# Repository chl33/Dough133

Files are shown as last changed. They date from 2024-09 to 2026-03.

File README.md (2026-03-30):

# Dough133 (v1.0.0)

Dough133 is a temperature-controlled container for proofing and fermenting sourdough.
It uses a small cooler and a PTC heater with a fan to heat the inside of the cooler.
A PCBA with an ESP32 controls the power supplied to the heater to regulate
 the temperature of the enclosure.

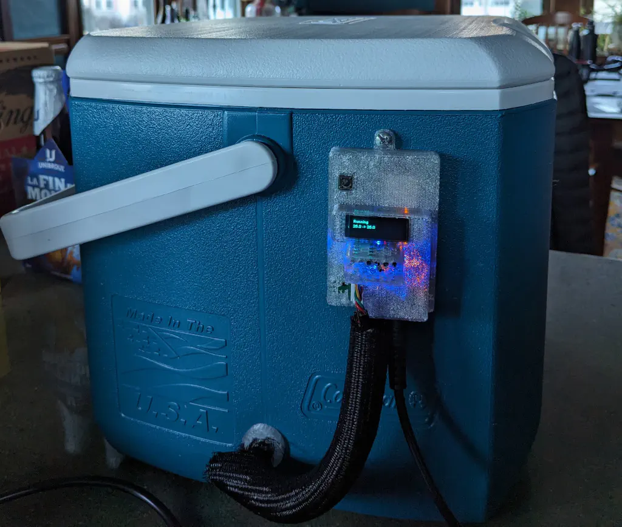
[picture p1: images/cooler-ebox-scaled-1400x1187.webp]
Doughh133


This repository contains:
- KiCAD design for the PCB.
- Source code for the device firmware.
- OpenSCAD design for 3D printed components.

[Instructions for the assembly](https://selectiveappeal.org/posts/dough133-assembly/)
 of the device are in this are at my blog.

Please also see the other entries describing this project:
- [Building a DIY Sourdough Proofer (Dough133)](https://selectiveappeal.org/posts/dough133/),
- [Dough133 Electronics: Designing a Custom ESP32 Controller for Proofing Sourdough](https://selectiveappeal.org/posts/dough133-electronics/), and
- [Dough133 Control: Yeast Welfare through Applied Mathematics](https://selectiveappeal.org/posts/dough133-control/).

Components needed for making this device, along with links and approximate price as of September
 2024:

| Item | Source  | Approximate cost  |
|---|---|---|
| Coleman 16 qt cooler | [Amazon](https://www.amazon.com/gp/product/B09HN13FN4) | $23 |
| PTC Air Heater 12V 100W | [AliExpress](https://www.aliexpress.us/item/3256803451720173.html) | $7 |
| DC 12V 5A Power Supply | [Amazon](https://www.amazon.com/gp/product/B01GEA8PQA)  | $12  |

## KiCAD

The circuit board design is in [KiCAD/](KiCAD/).

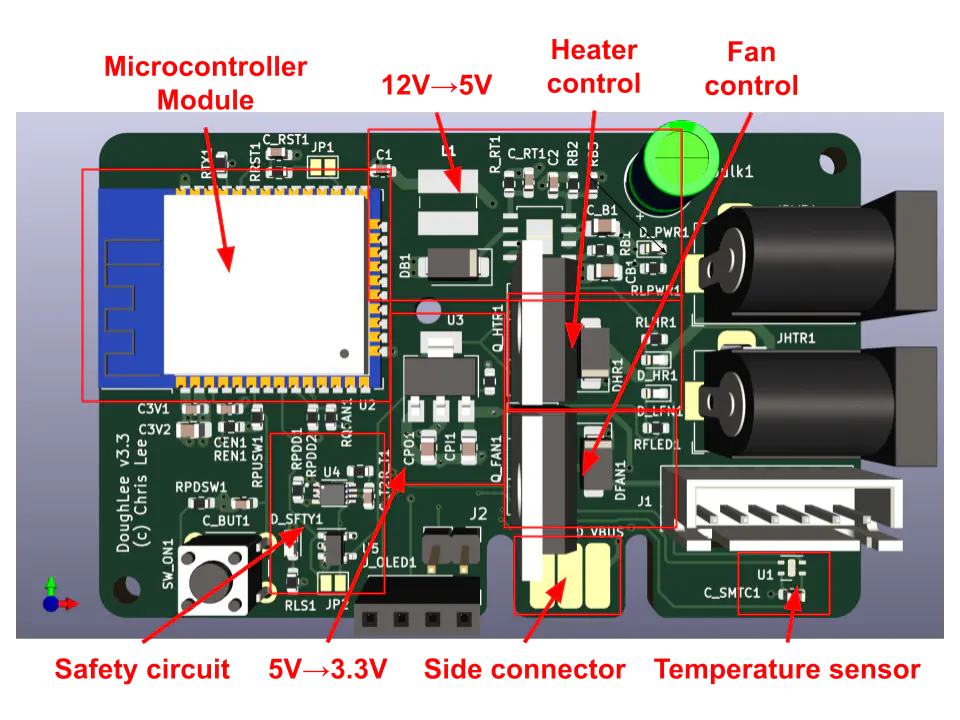
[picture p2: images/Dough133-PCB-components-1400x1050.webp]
Circuit board


These require footprints in [`chl33_library`](https://github.com/chl33/chl33_library.pretty) and symbols in [`chl33_kicad_sym`](https://github.com/chl33/chl33_kicad_sym).

## OpenSCAD

Designs for 3D-printable components are in [scad/](scad/).

The EBox is based on the [ProjectBox](https://github.com/chl33/ProjectBox) OpenSCAD system.

The heater mount secures the heater and temperature/humidity sensor inside the cooler.

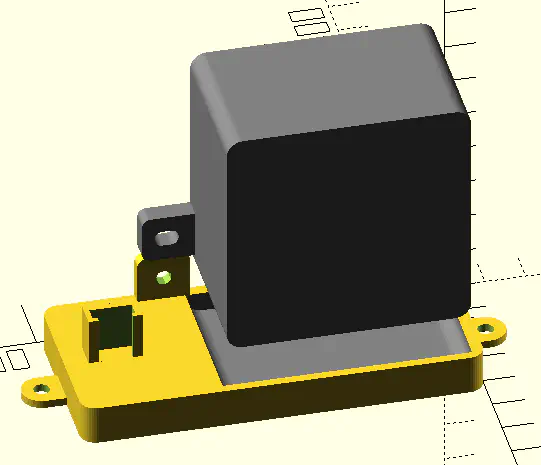
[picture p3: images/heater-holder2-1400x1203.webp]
Heater mount


The Cooler plug helps avoid heat leaking through the hole through which wires run from the
 heater mount through the wall of the cooler to the EBox.

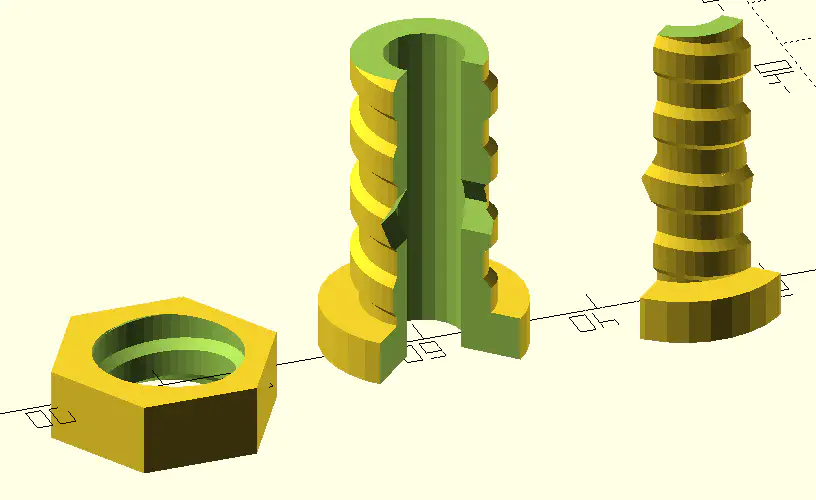
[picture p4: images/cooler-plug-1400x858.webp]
Cooler plug


## Software

The software is based on the [og3](https://github.com/chl33/og3) library and built
 using [PlatformIO](https://platformio.org/).

### Features

*   **Modern Web Interface:** A responsive Svelte-based UI for real-time status monitoring, PID tuning, and system configuration.
*   **PID Temperature Control:** Uses a Proportional-Integral-Derivative controller with feedforward to maintain precise temperature.
*   **Manual Fan Control:** Toggle the enclosure fan manually via the web interface.
*   **Home Assistant Integration:** Supports MQTT auto-discovery for seamless integration with Home Assistant as a generic thermostat.
*   **Safety Features:** Includes max/min temperature limits, sensor error detection, and safety hardware to cut heater power if the microprocessor is not running properly.

### Getting Started

#### Prerequisites

*   [PlatformIO](https://platformio.org/install) (CLI or VSCode extension).

#### Configuration

The project uses `ini` files for local configuration and secrets. You need to create `secrets.ini` and `secrets-usb.ini` based on the provided examples.

1.  **General Secrets:**
    Copy `secrets.ini.example` to `secrets.ini` and configure:
    ```ini
    [secrets]
    udpLogTarget = 192, 168, 1, 100  ; Optional: IP for UDP logging
    otaPassword = my_secure_password ; Password for Over-The-Air updates
    ```

2.  **Upload Configuration:**
    For USB flashing, copy `secrets-usb.ini.example` to `secrets-usb.ini`:
    ```ini
    [secrets]
    uploadProtocol = esptool
    uploadPort = /dev/ttyUSB0      ; Check your specific port (e.g., COM3 on Windows)
    uploadAuth =
    uploadHostPort =
    ```
    *(For OTA updates later, you can use `secrets-ota.ini`)*

#### Building and Flashing

1.  Connect the ESP32 board to your computer via USB.
2.  Build and upload the firmware:
    ```bash
    pio run -t upload
    ```
3.  Monitor the serial output to verify startup:
    ```bash
    pio device monitor
    ```

### Usage

#### Physical Interface

*   **Button:** Press the physical button to toggle temperature control ON or OFF.
*   **OLED Screen:** Displays the current state (Off, Running, Cooling), current temperature, and target temperature.

#### Web Interface

Once connected to WiFi, navigate to the device's IP address (displayed on the OLED).
*   **Status Page:** View current temperatures (Enclosure, Room), humidity, and heater status.
*   **Controls:** Enable/Disable the heater.
*   **Configuration:** Set the target temperature, ramp rates, and PID gains.

#### Home Assistant

Ensure your MQTT broker details are configured in the Web UI.
The device will automatically appear in Home Assistant as a climate device
 (Thermostat) if MQTT discovery is enabled.

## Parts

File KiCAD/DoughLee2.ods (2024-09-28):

Source: | /home/chris/KiCad/DoughLee2/DoughLee2.kicad_sch
Date: | Fri 12 Jan 2024 07:47:42 AM EST
Tool: | Eeschema 7.0.10-7.0.10~ubuntu22.04.1
Generator: | /usr/share/kicad/plugins/bom_csv_grouped_by_value_with_fp.py
Component Count: | 52
Ref | Qnty | Value | Cmp name | Footprint | Description | Vendor | DNP
C1 | 1 | 44uF (16V) | C | Capacitor_SMD:C_0603_1608Metric | Unpolarized capacitor
C2 | 1 | 180pF (50V) | C | Capacitor_SMD:C_0603_1608Metric | Unpolarized capacitor
C3V1 | 1 | 100nF | C | Capacitor_SMD:C_0603_1608Metric | Unpolarized capacitor
C3V2 | 1 | 10uF | C | Capacitor_SMD:C_0805_2012Metric_Pad1.18x1.45mm_HandSolder | Unpolarized capacitor
C_B1 | 1 | 4.7uF | C | Capacitor_SMD:C_0603_1608Metric | Unpolarized capacitor
C_BUT1 | 1 | 100nF | C | Capacitor_SMD:C_0603_1608Metric | Unpolarized capacitor
C_RT1 | 1 | 100pF | C | Capacitor_SMD:C_0603_1608Metric_Pad1.08x0.95mm_HandSolder | Unpolarized capacitor
C_SMTC1 | 1 | 100nF | C | Capacitor_SMD:C_0603_1608Metric | Unpolarized capacitor
C_T2 | 1 | 100nF | C | Capacitor_SMD:C_0603_1608Metric | Unpolarized capacitor
CB1 | 1 | 10nF (50V) | C | Capacitor_SMD:C_0805_2012Metric_Pad1.18x1.45mm_HandSolder | Unpolarized capacitor
Cbulk1 | 1 | 220uF (35Vx2) | C_Polarized | Capacitor_THT:CP_Radial_D6.3mm_P2.50mm | Polarized capacitor
CEN1 | 1 | 100nF | C | Capacitor_SMD:C_0603_1608Metric | Unpolarized capacitor
CPI1 | 1 | 10uF | C | Capacitor_SMD:C_0805_2012Metric_Pad1.18x1.45mm_HandSolder | Unpolarized capacitor
CPO1 | 1 | 47uF | C | Capacitor_SMD:C_0805_2012Metric_Pad1.18x1.45mm_HandSolder | Unpolarized capacitor
D_HR1 | 1 | LED | LED | LED_SMD:LED_0603_1608Metric | Light emitting diode
D_LFN1 | 1 | LED | LED | LED_SMD:LED_0603_1608Metric | Light emitting diode
D_PWR1 | 1 | BLU | LED | LED_SMD:LED_0603_1608Metric | Light emitting diode
DB1 | 1 | SS34 | D_Schottky | Diode_SMD:D_SMA | Schottky diode
DFAN1 | 1 | 1N4001 | 1N4001 | Diode_SMD:D_SMA | 50V 1A General Purpose Rectifier Diode, DO-41
DHR1 | 1 | SS34-E3/9AT | SS34-E3{brace}slash}9AT | Diode_SMD:D_SMA
J1 | 1 | Conn_01x06 | Conn_01x06 | Connector_JST:JST_XH_B6B-XH-A_1x06_P2.50mm_Vertical | Generic connector, single row, 01x06, script generated (kicad-library-utils/schlib/autogen/connector/)
J3 | 1 | Edge2x6_Connector | Edge2x6_Connector | Library:EdgeConnector_2x3
J_OLED1 | 1 | Conn_01x04_Female | Conn_01x04_Female | Connector_PinSocket_2.54mm:PinSocket_1x04_P2.54mm_Vertical | Generic connector, single row, 01x04, script generated (kicad-library-utils/schlib/autogen/connector/)
JHTR1 | 1 | Barrel_Jack | Barrel_Jack | Connector_BarrelJack:BarrelJack_Horizontal | DC Barrel Jack
JP2 | 1 | SolderJumper_2_Open | SolderJumper_2_Open | Jumper:SolderJumper-2_P1.3mm_Open_Pad1.0x1.5mm | Solder Jumper, 2-pole, open
JPWR1 | 1 | Barrel_Jack | Barrel_Jack | Connector_BarrelJack:BarrelJack_Horizontal | DC Barrel Jack
L1 | 1 | 100 μH | L | Library:CD54 | Inductor
Q_FAN1 | 1 | IRLB8721PBF | IRLB8721PBF | Package_TO_SOT_THT:TO-220-3_Vertical | 62A Id, 30V Vds, 8.7 mOhm Rds, N-Channel HEXFET Power MOSFET, TO-220
Q_HTR1 | 1 | IRLB8721PBF | IRLB8721PBF_1 | Package_TO_SOT_THT:TO-220-3_Vertical | 62A Id, 30V Vds, 8.7 mOhm Rds, N-Channel HEXFET Power MOSFET, TO-220
R_RT1 | 1 | 27k | R | Resistor_SMD:R_0603_1608Metric | Resistor
R_T1 | 1 | 100k | R | Resistor_SMD:R_0603_1608Metric | Resistor
RB1 | 1 | 33k | R | Resistor_SMD:R_0603_1608Metric | Resistor
RB2 | 1 | 43k | R | Resistor_SMD:R_0603_1608Metric | Resistor
RB3 | 1 | 8.2k | R | Resistor_SMD:R_0603_1608Metric | Resistor
REN1 | 1 | 10k | R | Resistor_SMD:R_0603_1608Metric | Resistor
RFLED1 | 1 | 1k | R | Resistor_SMD:R_0603_1608Metric | Resistor
RLHR1 | 1 | 1k | R | Resistor_SMD:R_0603_1608Metric | Resistor
RLPWR1 | 1 | 1k | R | Resistor_SMD:R_0603_1608Metric | Resistor
RPDD1, RPDD2 | 2 | 12k | R | Resistor_SMD:R_0603_1608Metric | Resistor
RPDSW1 | 1 | 10k | R | Resistor_SMD:R_0603_1608Metric | Resistor
RPUSW1 | 1 | 100k | R | Resistor_SMD:R_0603_1608Metric | Resistor
RQFAN1 | 1 | 490 | R | Resistor_SMD:R_0603_1608Metric | Resistor
RQHTR1 | 1 | 490 | R | Resistor_SMD:R_0603_1608Metric | Resistor
RTX1 | 1 | 470 | R | Resistor_SMD:R_0603_1608Metric | Resistor
SW_ON1 | 1 | SW_Push | SW_Push | Button_Switch_THT:SW_PUSH_6mm | Push button switch, generic, two pins
U1 | 1 | SHTC3 | SHTC3 | Sensor_Humidity:Sensirion_DFN-4-1EP_2x2mm_P1mm_EP0.7x1.6mm | Humidity and Temperature Sensor, +/-2%RH, +/-0.2degC, I2C, 1.62-3.6V, DFN-4
U2 | 1 | ESP32-WROOM-32 | ESP32-WROOM-32 | RF_Module:ESP32-WROOM-32 | RF Module, ESP32-D0WDQ6 SoC, Wi-Fi 802.11b/g/n, Bluetooth, BLE, 32-bit, 2.7-3.6V, onboard antenna, SMD
U3 | 1 | AMS1117-3.3 | AMS1117-3.3 | Package_TO_SOT_SMD:SOT-223-3_TabPin2 | 1A Low Dropout regulator, positive, 3.3V fixed output, SOT-223
U4 | 1 | SN74LVC1G123DCUR | SN74LVC1G123DCUR | Library:SOP50P310X90-8N
U5 | 1 | 74LVC1G08 | 74LVC1G08 | Library:SOT-23-5 | Single AND Gate, Low-Voltage CMOS
U_B1 | 1 | BD90610EFJ-CE2 | BD90610EFJ-CE2 | Library:BD90610EFJ-CE2

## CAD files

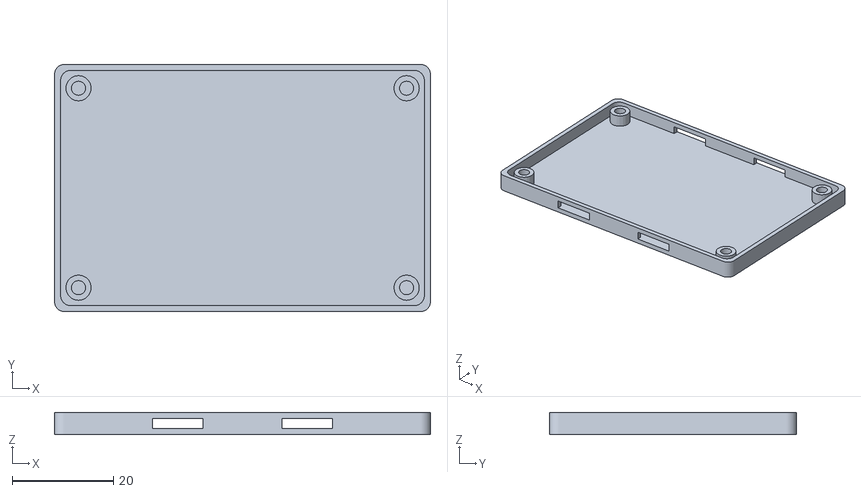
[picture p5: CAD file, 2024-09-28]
scad/Ebox/box_bottom.stl
74.2 x 48.8 x 4.40

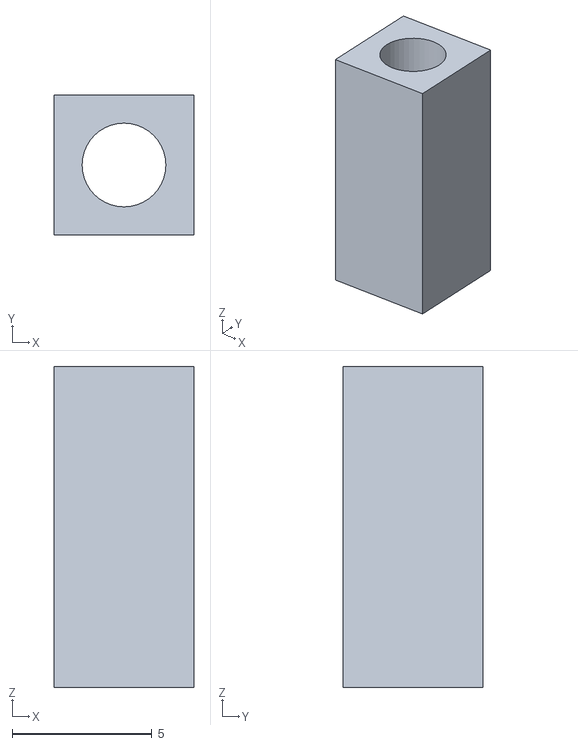
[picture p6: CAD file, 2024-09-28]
scad/Spacer/spacer.stl
5.00 x 5.00 x 11.5

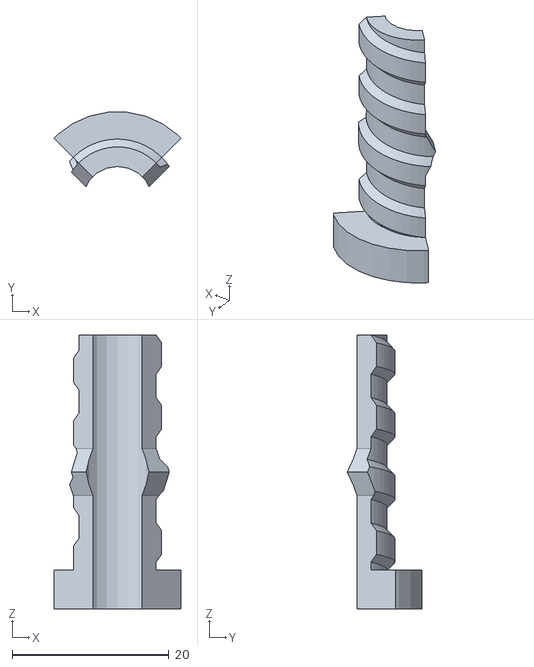
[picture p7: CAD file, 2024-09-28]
scad/CoolerPlug/plug_right.stl
16.2 x 9.54 x 35.0

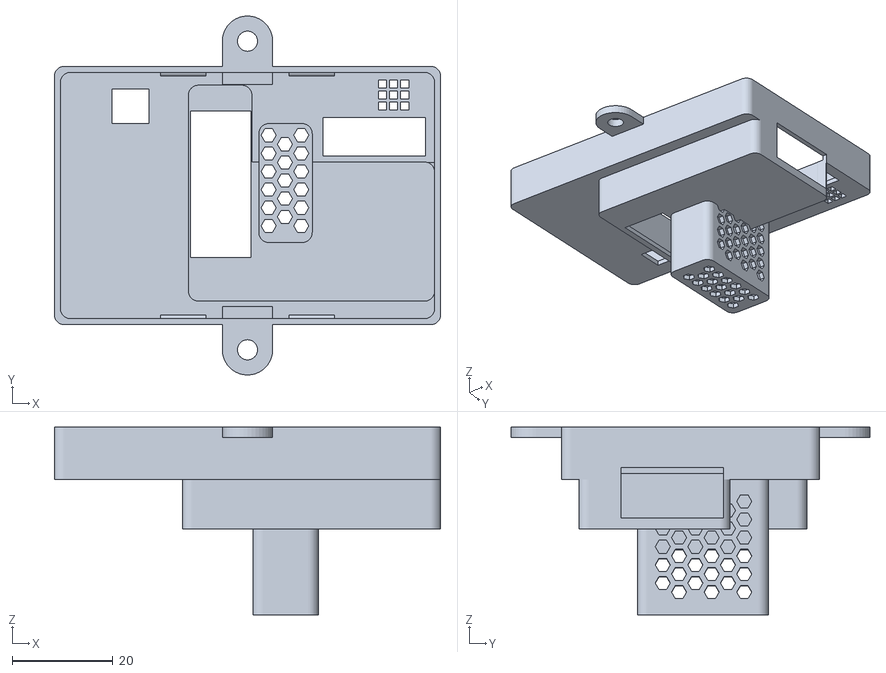
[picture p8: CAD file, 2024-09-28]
scad/Ebox/box_top.stl
76.7 x 71.2 x 37.2

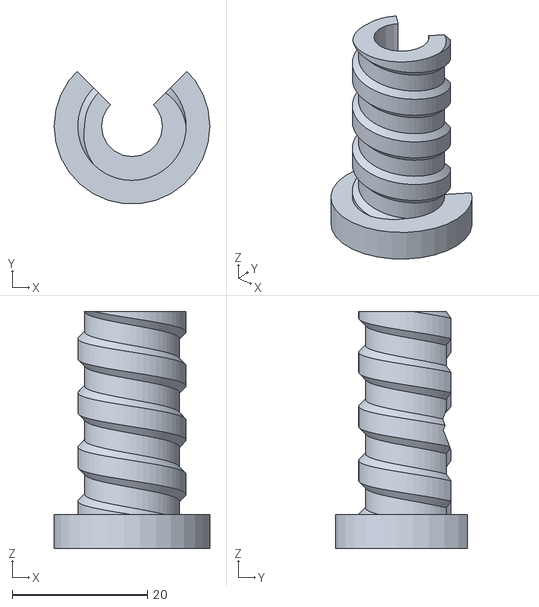
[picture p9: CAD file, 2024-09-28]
scad/CoolerPlug/plug_left.stl
23.0 x 19.5 x 35.0

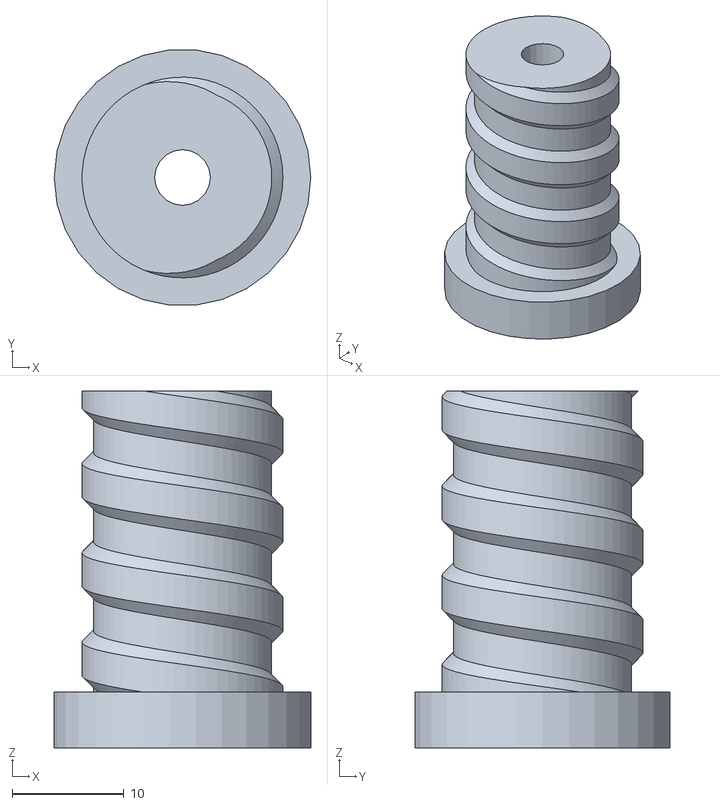
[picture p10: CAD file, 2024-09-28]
scad/CoolerPlug/plug.stl
23.0 x 22.9 x 32.0

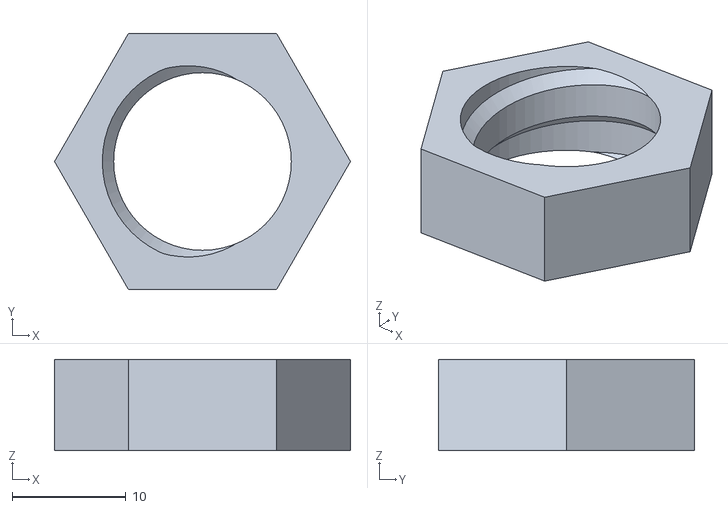
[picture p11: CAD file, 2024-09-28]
scad/CoolerPlug/nut.stl
26.0 x 22.5 x 8.02

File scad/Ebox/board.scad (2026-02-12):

// Copyright (c) 2026 Chris Lee and contributors.
// Licensed under the MIT license. See LICENSE file in the project root for details.

include <MCAD/units.scad>

include <ProjectBox/project_box.scad>
include <ProjectBox/screw_terminal.scad>

board_thickness = 1.6;
pad_space = 2.54;
board_dims = [27.5*pad_space, 17.5*pad_space, board_thickness];

mount_offset = pad_space;

module oled() {
  s = inch * 0.1;
  pin_len = 4;
  color("silver") {
    for (i = [0: 3]) {
      translate([s*i+pad_space, pad_space/2, -pin_len]) cube([0.25, 0.25, pin_len]);
    }
  }
  color("gray") cube([12, 38, 1]);
  translate([0, 4, 1]) color("black") cube([12, 28, 1]);
}

module doughheater_to_oled_frame() {
  u = pad_space;
  translate([u*9.3, 2, 11]) children();
}

module DoughHeater_board() {
  u = pad_space;
  bdz = board_dims[2];

  // Board imported from KiCad (VRML) -> Blender
  translate([board_dims[0]/2, board_dims[1]/2, 0.6]) color("white")
    import(file="DoughHeater.stl", convexity=3);

  doughheater_to_oled_frame() oled();
}

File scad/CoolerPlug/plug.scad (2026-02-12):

// Copyright (c) 2026 Chris Lee and contributors.
// Licensed under the MIT license. See LICENSE file in the project root for details.

include <BOSL/constants.scad>
include <MCAD/units.scad>
use <BOSL/shapes.scad>
use <BOSL/threading.scad>

hole_diam = 18;
hole_len = 22;
cap_depth = 5;
nut_depth = 8;
inner_diam = 9;
thread_depth = 1;

gap = 0.8;

screw_len = hole_len + cap_depth + nut_depth;
cap_diam = hole_diam + 5;

module right_side() {
  translate(-epsilon*Z) rotate(45, Z) union() {
    cube([20, 20, screw_len + 2*epsilon]);
    translate([10, 10, screw_len / 2]) {
      prismoid(size1=[20+3, 20+3], size2=[20, 20], h=3);
      translate(-3*Z) prismoid(size1=[20, 20], size2=[20+3, 20+3], h=3);
    }
  }
}

module plug() {
  difference() {
    union() {
      cylinder(cap_depth, cap_diam/2, cap_diam/2);
      translate(Z*screw_len/2)
	trapezoidal_threaded_rod(d=hole_diam-2*thread_depth, l=screw_len, pitch=8,
				 thread_depth=thread_depth,
				 thread_angle=45, left_handed=true, $fa=2, $fs=1);
    }
    translate(-Z*epsilon) {
      cylinder(screw_len + 2*epsilon, inner_diam/2, inner_diam/2, $fn=20);
    }
  }
}

module plug_left() {
  difference() {
    plug();
    right_side();    
  }
}

module plug_right() {
  intersection() {
    plug();
    right_side();    
  }
}

module nut() {
  nut_diam = hole_diam + 8;
  difference() {
    cyl(l=nut_depth + 2*epsilon, d=nut_diam, $fn=6);
      trapezoidal_threaded_rod(d=hole_diam-2*thread_depth+2*gap, l=screw_len, pitch=8,
			       thread_depth=1, thread_angle=45, left_handed=true, $fa=2, $fs=1);
  }
}


//plug_lef();
//plug_right();
//plug();
//nut();

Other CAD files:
scad/CoolerPlug/nut.scad
scad/CoolerPlug/plug_left.scad
scad/CoolerPlug/plug_right.scad
scad/CoolerPlug/test_plug.scad
scad/Ebox/Dough133_test.scad
scad/Ebox/box.scad
scad/Ebox/box_bottom.scad
scad/Ebox/box_top.scad
scad/Ebox/gui.scad
scad/Spacer/spacer.scad

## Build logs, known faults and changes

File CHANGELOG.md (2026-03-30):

# Changelog

All notable changes to this project will be documented in this file.

The format is based on [Keep a Changelog](https://keepachangelog.com/en/1.0.0/),
and this project adheres to [Semantic Versioning](https://semver.org/spec/v2.0.0.html).

## [1.0.0] - 2026-03-29

### Added
- New responsive Svelte web interface for status monitoring and configuration.
- JSON API for full device control and status reporting.
- Standardized `camelCase` naming for all API keys and internal variables.
- Manual fan control via web UI.
- Integrated "Run Test" command button in configuration page.
- Switch to `min_spiffs.csv` partition table to support OTA updates with the new web assets.

### Changed
- Reorganized web server routes (legacy HTML interface moved to `/old`).
- Improved PID control stability and configuration.
- Standardized variable naming across firmware and frontend.

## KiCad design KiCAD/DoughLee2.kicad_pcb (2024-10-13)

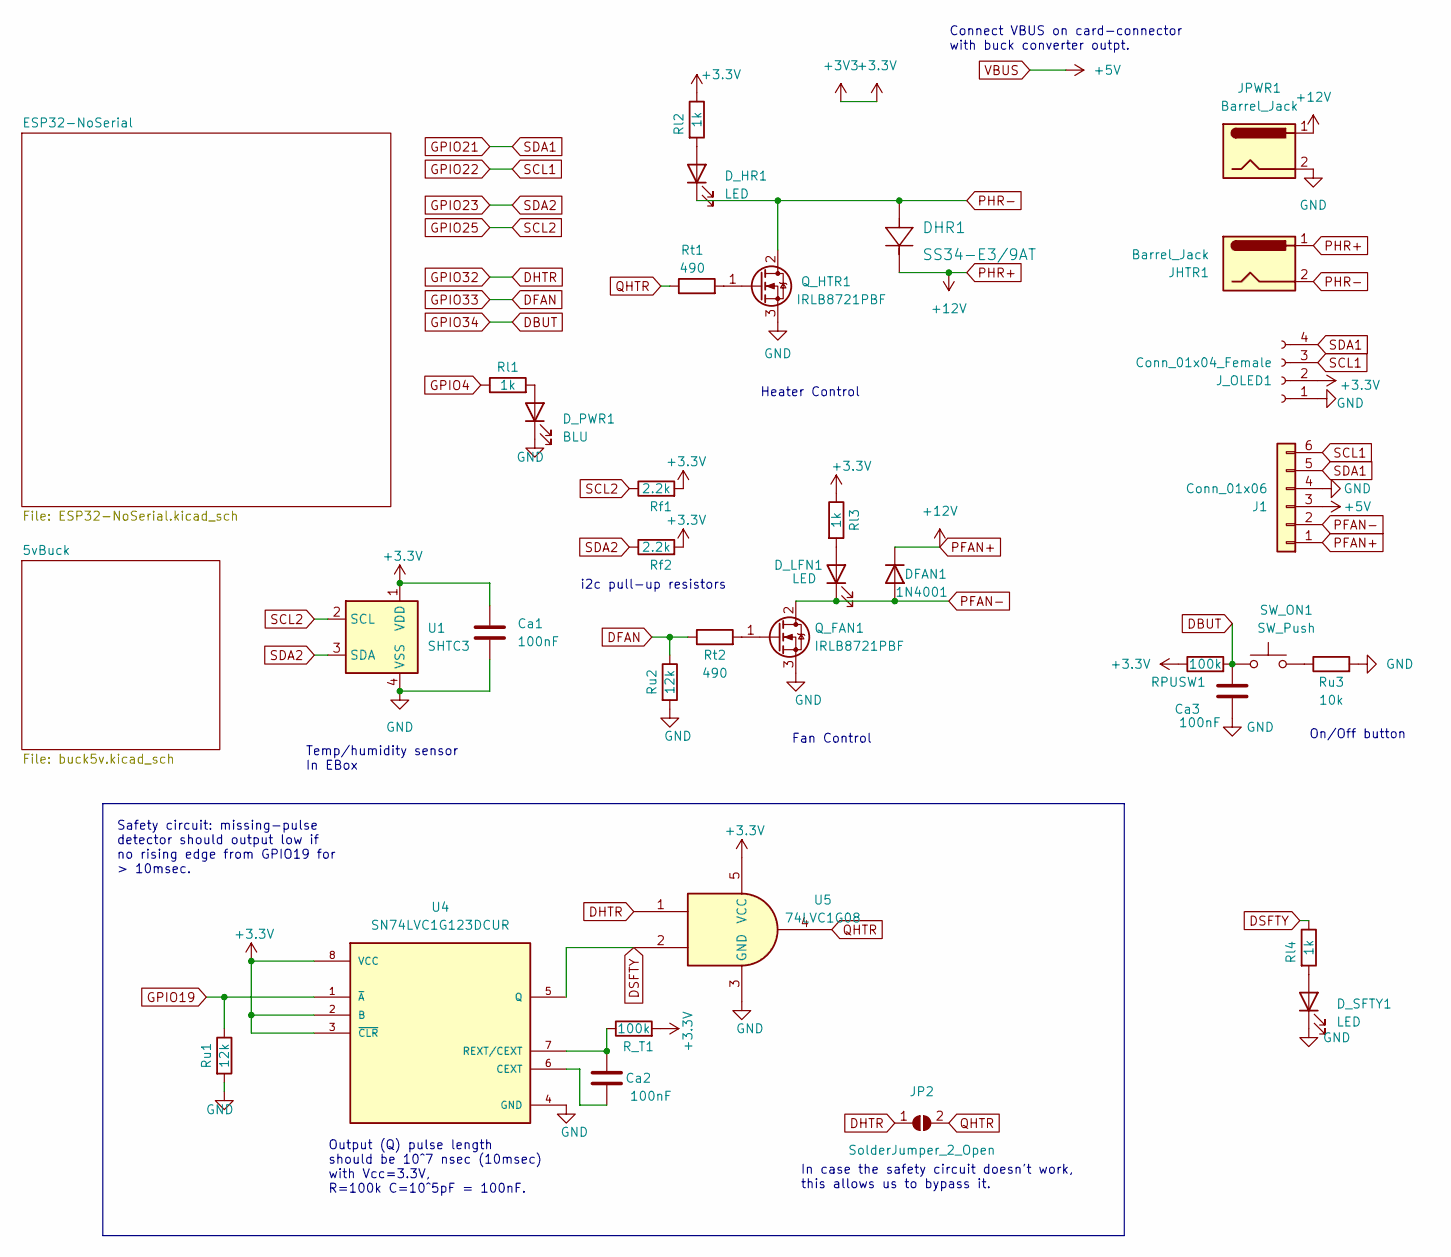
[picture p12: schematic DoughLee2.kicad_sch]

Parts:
Ca1, Ca2, Ca3: 100nF; C_0603_1608Metric
DFAN1: 1N4001; D_SMB
DHR1: SS34-E3/9AT; D_SMB
D_HR1: LED; LED_0603_1608Metric
D_LFN1: LED; LED_0603_1608Metric
D_PWR1: BLU; LED_0603_1608Metric
D_SFTY1: LED; LED_0603_1608Metric
J1: Conn_01x06; JST_XH_B6B-XH-A_1x06_P2.50mm_Vertical
JHTR1: Barrel_Jack; BarrelJack_Horizontal
JP2: SolderJumper_2_Open; SolderJumper-2_P1.3mm_Open_Pad1.0x1.5mm
JPWR1: Barrel_Jack; BarrelJack_Horizontal
J_OLED1: Conn_01x04_Female; PinSocket_1x04_P2.54mm_Vertical
Q_FAN1: IRLB8721PBF; TO-220-3_Vertical
Q_HTR1: IRLB8721PBF; TO-220-3_Vertical
RPUSW1: 100k; R_0603_1608Metric
R_T1: 100k; R_0603_1608Metric
Rf1, Rf2: 2.2k; R_0603_1608Metric
Rl1, Rl2, Rl3, Rl4: 1k; R_0603_1608Metric
Rt1, Rt2: 490; R_0603_1608Metric
Ru1, Ru2: 12k; R_0603_1608Metric
Ru3: 10k; R_0603_1608Metric
SW_ON1: SW_Push; SW_PUSH_6mm
U1: SHTC3; Sensirion_DFN-4-1EP_2x2mm_P1mm_EP0.7x1.6mm
U4: SN74LVC1G123DCUR; SOP50P310X90-8N
U5: 74LVC1G08; SOT-23-5

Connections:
+3.3V: Ca1.1, J_OLED1.2, RPUSW1.1, R_T1.2, Rf1.2, Rf2.2, Rl2.1, Rl3.1, U1.1 (VDD), U4.2 (B), U4.3 (~CLR), U4.8 (VCC), U5.5 (VCC); also elsewhere on the board
DBUT: Ca3.1, RPUSW1.2, SW_ON1.1; also elsewhere on the board
DFAN: Rt2.1, Ru2.1; also elsewhere on the board
DHTR: JP2.1 (A), U5.1; also elsewhere on the board
DSFTY: Rl4.1, U4.5 (Q), U5.2
GND: Ca1.2, Ca3.2, D_PWR1.1 (K), D_SFTY1.1 (K), J1.4, JPWR1.2, J_OLED1.1, Q_FAN1.3 (S), Q_HTR1.3 (S), Ru1.2, Ru2.2, Ru3.2, U1.4 (VSS), U4.4 (GND), U5.3 (GND); also elsewhere on the board
GPIO4: Rl1.1; also elsewhere on the board
GPIO19: Ru1.1, U4.1 (~A); also elsewhere on the board
GPIO21: J1.5, J_OLED1.4; also elsewhere on the board
GPIO22: J1.6, J_OLED1.3; also elsewhere on the board
GPIO23: Rf2.1, U1.3 (SDA); also elsewhere on the board
GPIO25: Rf1.1, U1.2 (SCL); also elsewhere on the board
unnamed: D_HR1.2 (A), Rl2.2
unnamed: D_LFN1.2 (A), Rl3.2
unnamed: D_PWR1.2 (A), Rl1.2
unnamed: D_SFTY1.2 (A), Rl4.2
unnamed: Q_FAN1.1 (G), Rt2.2
unnamed: Q_HTR1.1 (G), Rt1.2
unnamed: Ru3.1, SW_ON1.2
unnamed: Ca2.2, U4.6 (CEXT)
unnamed: Ca2.1, R_T1.1, U4.7 (REXT/CEXT)
PFAN+: DFAN1.1 (K), DHR1.1 (ANODE), J1.1, JHTR1.1, JPWR1.1; also elsewhere on the board
PFAN-: DFAN1.2 (A), D_LFN1.1 (K), J1.2, Q_FAN1.2 (D)
PHR-: DHR1.2 (CATHODE), D_HR1.1 (K), JHTR1.2, Q_HTR1.2 (D)
QHTR: JP2.2 (B), Rt1.1, U5.4
VBUS: J1.3; also elsewhere on the board

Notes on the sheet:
On/Off button
Heater Control
In case the safety circuit doesn't work, this allows us to bypass it.
Connect VBUS on card-connector with buck converter outpt.
i2c pull-up resistors
Fan Control
Safety circuit: missing-pulse detector should output low if no rising edge from GPIO19 for > 10msec.
Output (Q) pulse length should be 10^7 nsec (10msec) with Vcc=3.3V, R=100k C=10^5pF = 100nF.
Temp/humidity sensor In EBox

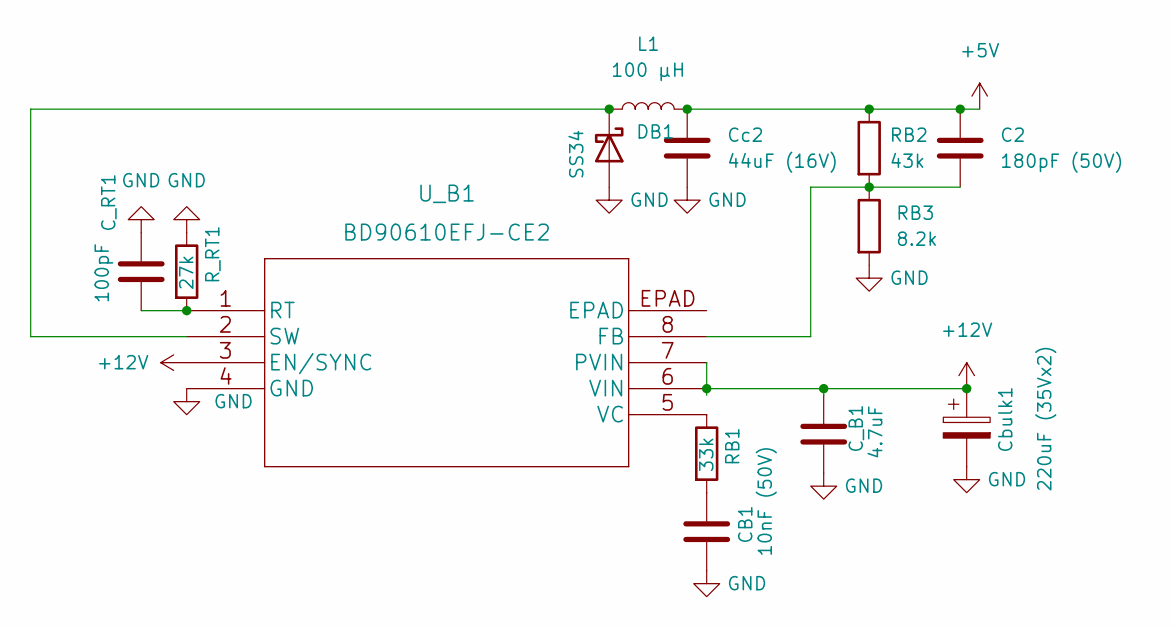
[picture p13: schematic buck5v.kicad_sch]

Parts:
C2: 180pF (50V); C_0603_1608Metric
CB1: 10nF (50V); C_0805_2012Metric_Pad1.18x1.45mm_HandSolder
C_B1: 4.7uF; C_0805_2012Metric_Pad1.18x1.45mm_HandSolder
C_RT1: 100pF; C_0603_1608Metric_Pad1.08x0.95mm_HandSolder
Cbulk1: 220uF (35Vx2); CP_Radial_D6.3mm_P2.50mm
Cc2: 44uF (16V); C_0603_1608Metric
DB1: SS34; D_SMA
L1: 100 μH; CD54
RB1: 33k; R_0603_1608Metric
RB2: 43k; R_0603_1608Metric
RB3: 8.2k; R_0603_1608Metric
R_RT1: 27k; R_0603_1608Metric
U_B1: BD90610EFJ-CE2; HTSOP-J8_ROM

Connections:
GND: CB1.2, C_B1.2, C_RT1.1, Cbulk1.2, Cc2.2, DB1.2 (A), RB3.2, R_RT1.1, U_B1.4 (GND); also elsewhere on the board
unnamed: CB1.1, RB1.2
unnamed: DB1.1 (K), L1.1, U_B1.2 (SW)
unnamed: C2.2, RB2.2, RB3.1, U_B1.8 (FB)
unnamed: C_RT1.2, R_RT1.2, U_B1.1 (RT)
unnamed: RB1.1, U_B1.5 (VC)
PFAN+: C_B1.1, Cbulk1.1, U_B1.3 (EN/SYNC), U_B1.6 (VIN), U_B1.7 (PVIN); also elsewhere on the board
VBUS: C2.1, Cc2.1, L1.2, RB2.1; also elsewhere on the board

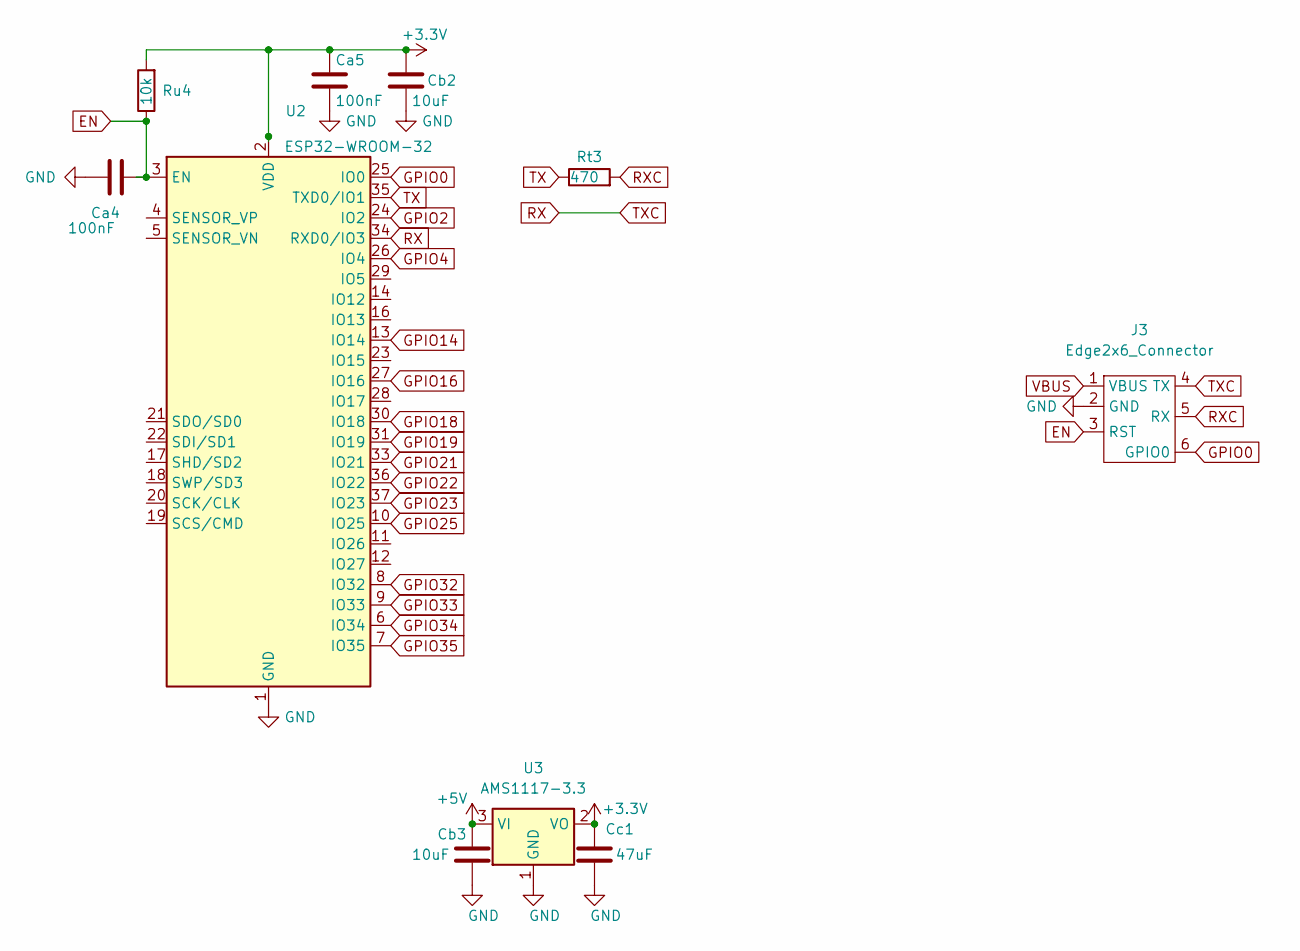
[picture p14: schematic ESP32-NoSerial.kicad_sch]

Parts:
Ca4, Ca5: 100nF; C_0603_1608Metric
Cb2, Cb3: 10uF; C_0805_2012Metric_Pad1.18x1.45mm_HandSolder
Cc1: 47uF; C_0805_2012Metric_Pad1.18x1.45mm_HandSolder
J3: Edge2x6_Connector; EdgeConnector_2x3
Rt3: 470; R_0603_1608Metric
Ru4: 10k; R_0603_1608Metric
U2: ESP32-WROOM-32
U3: AMS1117-3.3; SOT-223-3_TabPin2

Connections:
+3.3V: Ca5.1, Cb2.1, Cc1.1, Ru4.2, U2.2 (VDD), U3.2 (VO); also elsewhere on the board
DBUT: U2.6 (IO34); also elsewhere on the board
DFAN: U2.9 (IO33); also elsewhere on the board
DHTR: U2.8 (IO32); also elsewhere on the board
EN: Ca4.2, J3.3 (RST), Ru4.1, U2.3 (EN)
GND: Ca4.1, Ca5.2, Cb2.2, Cb3.2, Cc1.2, J3.2 (GND), U2.1 (GND), U2.15 (GND), U2.38 (GND), U2.39 (GND), U3.1 (GND); also elsewhere on the board
GPIO0: J3.6 (GPIO0), U2.25 (IO0)
GPIO2: U2.24 (IO2)
GPIO4: U2.26 (IO4); also elsewhere on the board
GPIO14: U2.13 (IO14)
GPIO16: U2.27 (IO16); also elsewhere on the board
GPIO18: U2.30 (IO18)
GPIO19: U2.31 (IO19); also elsewhere on the board
GPIO21: U2.33 (IO21); also elsewhere on the board
GPIO22: U2.36 (IO22); also elsewhere on the board
GPIO23: U2.37 (IO23); also elsewhere on the board
GPIO25: U2.10 (IO25); also elsewhere on the board
GPIO35: U2.7 (IO35)
RX: J3.4 (TX), U2.34 (RXD0/IO3)
RXC: J3.5 (RX), Rt3.2
TX: Rt3.1, U2.35 (TXD0/IO1)
VBUS: Cb3.1, J3.1 (VBUS), U3.3 (VI); also elsewhere on the board

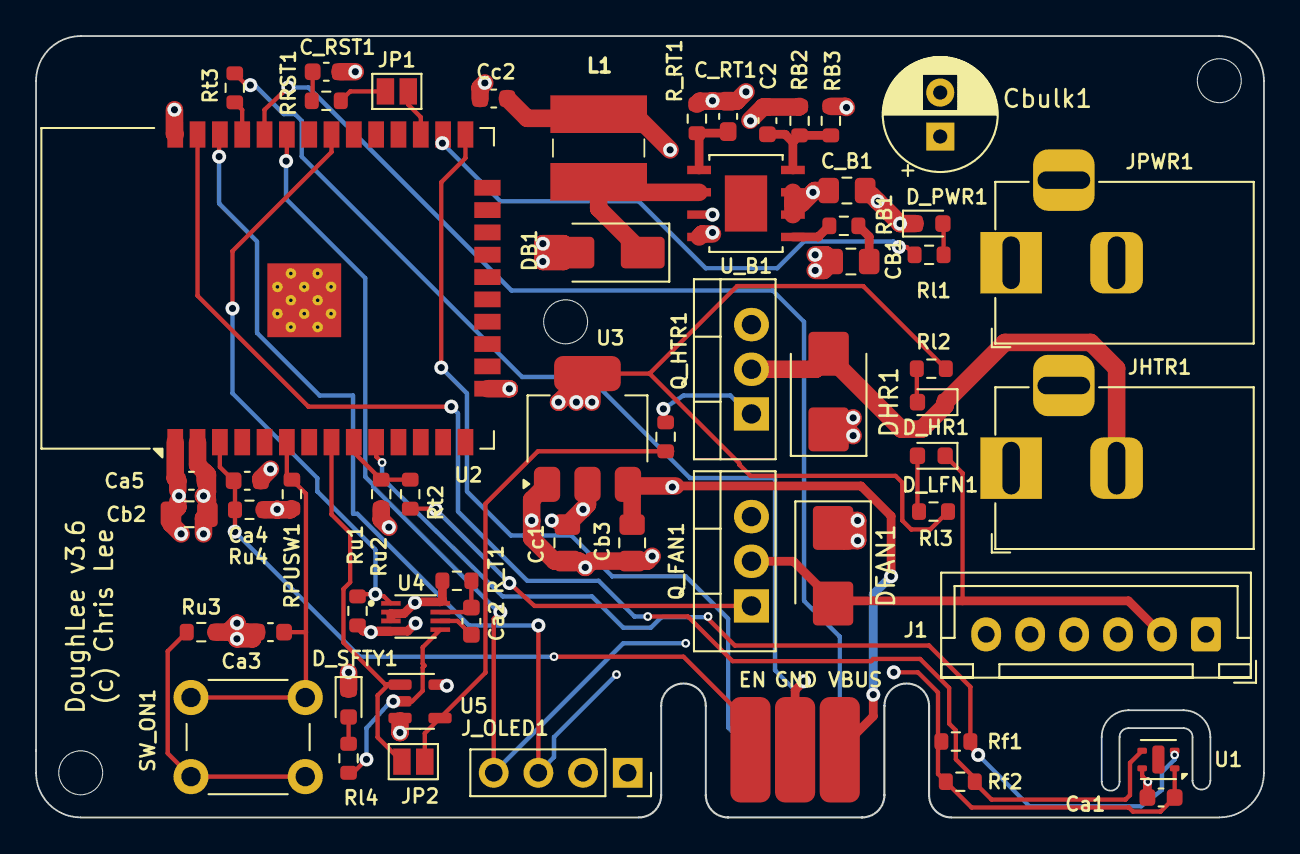
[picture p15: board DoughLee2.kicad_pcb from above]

Board: 4 copper layers, 69.8 x 44.5 mm, 59 parts (0 on the bottom side), 39 nets.

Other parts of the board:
C_RST1: 100nF; C_0603_1608Metric
JP1: SolderJumper_2_Open; SolderJumper-2_P1.3mm_Open_Pad1.0x1.5mm
RRST1: 470; R_0603_1608Metric

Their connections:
GND: C_RST1.2; also elsewhere on the board
GPIO16: JP1.2 (B); also elsewhere on the board
unnamed: JP1.1 (A), RRST1.2
RST: C_RST1.1, RRST1.1

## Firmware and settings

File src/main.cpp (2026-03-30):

// Copyright (c) 2026 Chris Lee and contributors.
// Licensed under the MIT license. See LICENSE file in the project root for details.

#include <Arduino.h>
#include <LittleFS.h>
#include <og3/blink_led.h>
#include <og3/constants.h>
#include <og3/din.h>
#include <og3/ha_app.h>
#include <og3/html_table.h>
#include <og3/kernel_filter.h>
#include <og3/oled_display_ring.h>
#include <og3/oled_wifi_info.h>
#include <og3/pid.h>
#include <og3/pwm.h>
#include <og3/relay.h>
#include <og3/shtc3.h>
#include <og3/units.h>
#include <og3/variable.h>
#include <og3/web.h>

#include <algorithm>
#include <cmath>
#include <cstring>
#include <functional>
#include <limits>

#include "svelteesp32async.h"

#define VERSION "1.0.0"

// TODO(chrishl):
//  - Get board temperature working.
namespace og3 {

static const char kManufacturer[] = "Chris Lee";
static const char kModel[] = "Doughl33";
static const char kSoftware[] = "Doughl33 v" VERSION;

// Hardware config
// -- Pin assignments --
constexpr uint8_t kButtonPin = 34;
constexpr uint8_t kRelayHeaterPin = 32;
constexpr uint8_t kSafetyPWMPin = 19;
constexpr uint8_t kRelayFanPin = 33;
constexpr uint8_t kPowerLEDPin = 4;
constexpr uint8_t kSda2 = 23;
constexpr uint8_t kScl2 = 25;

// State machine config.
constexpr int kUpdateOnMsec = 1 * kMsecInSec;
constexpr int kUpdateOffMsec = 10 * kMsecInSec;
constexpr int kHeaterCooldownMsec = 90 * kMsecInSec;
constexpr double kHeaterPwmFrequency = 100;  // Pwm::kAnalogWriteFreqMin;  // 100Hz.
constexpr double kSafetyPwmFrequency = 200;
// Time to turn on relay from web button press.
constexpr int kFanOnMsec = 60 * kMsecInSec;

constexpr float kDefaultTargetTemp = 27.0f;
constexpr float kDefaultMinValidTemp = 10.0f;
constexpr float kDefaultMaxValidTemp = 70.0f;
constexpr float kDefaultCtlP = 0.25f;
constexpr float kDefaultCtlI = 0.001f;
constexpr float kDefaultCtlD = 5.0f;
constexpr float kDefaultCtlIMin = -0.15f;
constexpr float kDefaultCtlIMax = 0.15f;
constexpr float kDefaultCtlFFPerDeltaC = 0.01f;
constexpr float kDefaultRampRate = 0.05f;  // °C/sec
constexpr float kDefaultFFPerRate = 0.0f;  // pwm / (°C/sec)
constexpr float kTargetTempMax = 35.0f;
constexpr float kTargetTempMin = 15.0f;

constexpr uint8_t kPwmChannel = 0;
constexpr uint8_t kSafetyPwmChannel = 1;
constexpr uint8_t kPwmResolution = 16;

// Delay between updates of the OLED.
constexpr unsigned kOledSwitchMsec = 5000;

static const char kEnclosureTemperature[] = "enclosure_temp";
static const char kRoomTemperature[] = "room_temp";
static const char kFilteredTemperature[] = "filt_temp";
static const char kFilteredDTemperature[] = "filt_d_temp";
static const char kTargetTemperature[] = "target_temp";
static const char kEnclosureHumidity[] = "enclosure_humidity";
static const char kRoomHumidity[] = "room_humidity";
static const char kHeater[] = "heater";
static const char kFan[] = "fan";
static const char kHeaterState[] = "heater_state";
static const char kHeaterError[] = "heater_error";
static const char kSafetyPWM[] = "safety_pwm";
static const char kCommandP[] = "cmd_p";
static const char kCommandD[] = "cmd_d";
static const char kCommandI[] = "cmd_i";
static const char kCommandFF[] = "cmd_ff";
static const char kTestCommand[] = "cmd_test";
static const char kTestCommandTime[] = "cmd_test_test";

static const char kHtrMode[] = "htr_mode";
static const char kFanMode[] = "fan_mode";
static const char kOff[] = "off";
static const char kHeat[] = "heat";
static const char kHigh[] = "high";

#if defined(LOG_UDP) && defined(LOG_UDP_ADDRESS)
constexpr App::LogType kLogType = App::LogType::kUdp;
#else
constexpr App::LogType kLogType = App::LogType::kSerial;  // kSerial
#endif

HAApp s_app(HAApp::Options(kManufacturer, kModel,
                           WifiApp::Options()
                               .withSoftwareName(kSoftware)
                               .withDefaultDeviceName("doughl33")
#if defined(LOG_UDP) && defined(LOG_UDP_ADDRESS)
                               .withUdpLogHost(IPAddress(LOG_UDP_ADDRESS))

#endif
                               .withOta(OtaManager::Options(OTA_PASSWORD))
                               .withApp(App::Options().withLogType(kLogType))));

// Have oled display IP address or AP status.
OledWifiInfo wifi_infof(&s_app.tasks());

VariableGroup s_vg("dough");
VariableGroup s_cvg("dough_cfg");
VariableGroup s_cmdvg("dough_cmd");

DIn s_button_reader("power_button", &s_app.module_system(), kButtonPin, "power button", s_vg);

// void onConfigLoad();

const float kCommandMax = 1.0f;
const float kCommandMin = 0.0f;
const float kIMax = kDefaultCtlIMax;
const float kFeedforward = 0.0f;
const float kIMin = kDefaultCtlIMin;

PID s_pid(PID::Gains(kDefaultCtlP, kDefaultCtlI, kDefaultCtlD)
              .withCommandMax(kCommandMax)
              .withCommandMin(kCommandMin)
              .withIMax(kDefaultCtlIMax)
              .withIMin(kDefaultCtlIMin),
          s_vg, s_cvg, s_cmdvg);

Shtc3 s_shtc3_enclosure(kEnclosureTemperature, kEnclosureHumidity, &s_app.module_system(),
                        "enclosure temperature", s_vg, true, true);
Shtc3 s_shtc3_room(kRoomTemperature, kRoomHumidity, &s_app.module_system(), "room temperature",
                   s_vg, true, true, &Wire1);

Relay s_relay_fan(kFan, &s_app.tasks(), kRelayFanPin, "fan", true, s_vg);

// PWM to regulate heater power
Pwm s_pwm_heater(kHeater, kRelayHeaterPin, kPwmChannel, kPwmResolution, &s_app.module_system(),
                 kHeaterPwmFrequency);
// PWM to enable the heater.  If this stops, the safety circuit will stop the heater signal.
Pwm s_pwm_safety(kSafetyPWM, kSafetyPWMPin, kSafetyPwmChannel, kPwmResolution,
                 &s_app.module_system(), kSafetyPwmFrequency);

// Control of the power/mode LED.
BlinkLed s_blink("power", kPowerLEDPin, &s_app, 500, false /*on-low*/);

void heaterOn(float duty) {
  s_pwm_heater.setDutyF(duty);  // Set the heater power level via PWM ratio.
  s_pwm_safety.setDutyF(0.5);   // This PWM signal allows heater power to pass to the MOSFET.
}

void heaterOff() {
  s_pwm_heater.setDutyF(0.0f);  // Turn off the heater power.
  s_pwm_safety.setDutyF(0.0f);  // Disable the safety PWM signal.
}

KernelFilter s_temp_filter(
    {
        .name = kFilteredTemperature,
        .units = units::kCelsius,
        .description = "filtered enclosure temperature",
        .var_flags = 0,
        .sigma = 20.0,
        .decimals = 2,
        .size = 20,
    },
    &s_app.module_system(), s_vg);
KernelFilter s_d_temp_filter(
    {
        .name = kFilteredDTemperature,
        .units = "°C/sec",
        .description = "filtered enclosure temperature change",
        .var_flags = 0,
        .sigma = 15.0,
        .decimals = 2,
        .size = 15,
    },
    &s_app.module_system(), s_vg);

OledDisplayRing s_oled(&s_app.module_system(), "DoughL33", kOledSwitchMsec, Oled::kTenPt);

class TempControl : public Module {
 public:
  enum State {
    kStateDisabled,  // no heating
    kStateEnabled,   // heater control is enabled
    kStateCooldown,  // run fan after heating to cooldown
    kStateError,     // a problem was detected.
    kStateCommand,   // constant-output test state (m_test_command)
  };

  static const char* state_names[];

  static constexpr float kUninitializedTemp = -100.0f;
  static constexpr unsigned kCfgFlag = (VariableBase::kSettable | VariableBase::kConfig);
  static constexpr unsigned kNoFlag = 0;

  TempControl()
      : Module("temp_ctl", &s_app.module_system()),
        m_scheduler(&s_app.tasks()),
        m_state("state", kStateDisabled, "heater state", kStateCommand, state_names, kNoFlag, s_vg),
        m_temp_min_ok("tempMinOk", kDefaultMinValidTemp, units::kCelsius, "Min valid temperature",
                      kCfgFlag, 1, s_cvg),
        m_temp_max_ok("tempMaxOk", kDefaultMaxValidTemp, units::kCelsius, "Max valid temperature",
                      kCfgFlag, 1, s_cvg),
        m_ctl_ff_per_delta_c("ctlFeedforwardPerDeltaC", kDefaultCtlFFPerDeltaC, "pwm/deltaC",
                             "FF per deltaC", kCfgFlag, 3, s_cvg),
        m_set_temp("setTemp", kDefaultTargetTemp, units::kCelsius, "Target Temperature", kCfgFlag,
                   1, s_cmdvg),
        m_ramp_rate("rampRate", kDefaultRampRate, "°C/s", "Ramp Rate", kCfgFlag, 3, s_cvg),
        m_ff_per_rate("feedforwardPerRate", kDefaultFFPerRate, "pwm/(°C/s)", "FF per Rate",
                      kCfgFlag, 3, s_cvg),
        m_test_command("testCommand", 0.0f, "pwm", "Test command", kCfgFlag, 3, s_cmdvg),
        m_test_command_time("testCommandSec", 0.0f, "sec", "Test command sec", kCfgFlag, 1,
                            s_cmdvg),
        m_heat_mode("heatMode", kOff, "", "heater mode", kNoFlag, s_vg),
        m_fan_mode("fanMode", kOff, "", "fan mode", kNoFlag, s_vg) {
    add_init_fn([this]() {
      s_oled.addDisplayFn([this]() { show_state(); });
      auto* had = &s_app.ha_discovery();
      had->addDiscoveryCallback([this](HADiscovery* had, JsonDocument* json) -> bool {
        return this->haDiscovery(had, json);
      });
      had->addDiscoveryCallback([this](HADiscovery* had, JsonDocument* json) {
        return had->addEnum(json, m_state, ha::device_type::kSensor, nullptr);
      });
      had->addDiscoveryCallback([this](HADiscovery* had, JsonDocument* json) {
        return had->addBinarySensor(json, s_relay_fan.isHighVar(),
                                    ha::device_class::binary_sensor::kRunning);
      });
    });  // end of init-fn
  }

  void setTargetTemp(float target) { m_set_temp = target; }

  bool enabled() const { return m_state.value() == kStateEnabled; }

  void setEnable() {
    // Enable control from current state.
    switch (m_state.value()) {
      case kStateEnabled:
        break;
      case kStateDisabled:
      case kStateCooldown:
      case kStateError:
      case kStateCommand:
        // Make sure feedforward temperature will be recomputed if control is re-enabled.
        m_initial_temp = kUninitializedTemp;
        s_pid.feedforward() = 0.0f;
        // Start ramping from current temperature
        if (s_shtc3_enclosure.read()) {
          s_pid.target() = s_shtc3_enclosure.temperature();
          s_pid.d_target() = 0.0f;
        } else {
          s_pid.target() = m_set_temp.value();
          s_pid.d_target() = 0.0f;
        }
        setState(kStateEnabled, 100);
        break;
    }
  }

  void setDisable() {
    // Disable control from current state.
    switch (m_state.value()) {
      case kStateEnabled:
      case kStateCommand:
        setState(kStateCooldown, 100);
        break;
      case kStateDisabled:
      case kStateCooldown:
        break;
      case kStateError:
        setState(kStateDisabled, 100);
        break;
    }
  }

  void toggleEnable() {
    if (enabled()) {
      s_app.log().log("Disabling temperature control.");
      setDisable();
    } else {
      s_app.log().log("Enabling temperature control.");
      setEnable();
    }
    show_state();  // show on OLED
  }

  void delaySetEnable(bool enable) {
    if (!enable && enabled()) {
      m_scheduler.runIn(1, [this]() { setDisable(); });
    } else if (enable && !enabled()) {
      m_scheduler.runIn(1, [this]() { setEnable(); });
    }
  }

  void delaySetTestCommand() {
    m_scheduler.runIn(1, [this]() { setState(kStateCommand, kUpdateOnMsec); });
  }

  void setFanOn() { mqttSetFanMode("api", kHigh, strlen(kHigh)); }
  void setFanOff() { mqttSetFanMode("api", kOff, strlen(kOff)); }

  long msecInState() const { return millis() - m_last_state_change_msec; }
  float initialTemp() const { return m_initial_temp; }
  float testCommand() const { return m_test_command.value(); }
  float testCommandTime() const { return m_test_command_time.value(); }

  void turnFanOff() {
    if (m_fan_mode.value() == kOff) {
      s_relay_fan.turnOff();
    } else {
      s_relay_fan.turnOn();
    }
  }
  void turnFanOn() { s_relay_fan.turnOn(); }

  void show_state() {
    char display[80];
    const State state = m_state.value();
    s_shtc3_enclosure.read();
    if (state == kStateEnabled) {
      snprintf(display, sizeof(display), "%s\n%.1f -> %.1f", state_names[m_state.value()],
               s_shtc3_enclosure.temperature(), s_pid.target().value());
      s_oled.setFontSize(Oled::kTenPt);
    } else {
      snprintf(display, sizeof(display), "%s %.1f C", state_names[m_state.value()],
               s_shtc3_enclosure.temperature());
      s_oled.setFontSize(Oled::kSixteenPt);
    }
    s_oled.display(display);
  }

  void update() {
    if (!s_shtc3_enclosure.read() && m_state.value() != kStateDisabled) {
      s_app.log().logf("Failed to read SHTC3 enclosure sensor");
      setState(kStateError, 10 * kMsecInSec);
    }
    if (!s_shtc3_room.read()) {
      static bool s_warned = false;  // Not yet working, so only warn once.
      if (!s_warned) {
        s_app.log().logf("Failed to read SHTC3 room sensor");
        s_warned = true;
      }
    }
    const long now_msec = millis();
    const float temp = s_shtc3_enclosure.temperature();
    const bool temp_ok = temp >= m_temp_min_ok.value() && temp <= m_temp_max_ok.value();
    const float now_sec = now_msec * 1e-3;

    if (!temp_ok) {
      s_app.log().logf("Temperature %.1f outside valid range %.1f-%.1f", temp,
                       m_temp_min_ok.value(), m_temp_min_ok.value());
      setState(kStateError, 10 * kMsecInSec);
    }

    // Store the enclosure temperature when control is first enabled.
    if (m_state.value() == kStateEnabled && m_initial_temp == kUninitializedTemp) {
      m_initial_temp = temp;
    }

    // Return a target d_temp of -ramp_rate or ramp_rate, unless within a degree of them
    //  target, in which case scale ramp linearly to zero when error is zero.
    auto compute_target_d_temp = [this](float goal, float current_target) {
      const float error = goal - current_target;
      const float scale = (error > 1.0    ? 1.0      // increase at full-ramp rate.
                           : error < -1.0 ? -1.0     // decrease at full-ramp rate.
                                          : error);  // increase/decrease scaled by error.
      return scale * m_ramp_rate.value();
    };

    // Ramping and Feedforward Logic
    if (m_state.value() == kStateEnabled && m_last_msec > 0) {
      const float dt = (now_msec - m_last_msec) * 1.0e-3;
      if (dt > 0.0f && dt < 2.0f) {  // Sanity check on dt
        const float current_target = s_pid.target().value();
        const float target_d_temp = compute_target_d_temp(m_set_temp.value(), current_target);
        const float delta_target = target_d_temp * dt;
        const bool is_close = std::abs(m_set_temp.value() - current_target) < 0.05;
        const float next_target = is_close ? m_set_temp.value() : current_target + delta_target;
        s_pid.target() = next_target;
        s_pid.d_target() = compute_target_d_temp(next_target, temp);

        // Calculate Feedforward
        // 1. Dynamic FF: Power required to change temperature (Heat Capacity)
        const float dynamic_ff = target_d_temp * m_ff_per_rate.value();

        // 2. Static FF: Power required to maintain delta T (Insulation Loss)
        const float static_ff = (next_target - m_initial_temp) * m_ctl_ff_per_delta_c.value();

        s_pid.feedforward() = static_ff + dynamic_ff;
      }
    }

    // Track filtered temperature and temperature derivatives.
    float filt_d_temp = 0.0f;
    if (temp_ok) {
      s_temp_filter.addSample(now_sec, temp);
      if (m_last_temp != 0.0f) {
        const float delta_temp = temp - m_last_temp;
        const float delta_time = (now_msec - m_last_msec) * 1.0e-3;
        const float dtemp = delta_temp / delta_time;
        filt_d_temp = s_d_temp_filter.addSample(now_sec, dtemp);
      }
      m_last_temp = temp;
      m_last_msec = now_msec;
    }

    switch (m_state.value()) {
      case kStateDisabled:
        heaterOff();
        turnFanOff();
        sameState(kUpdateOffMsec);
        break;
      case kStateCooldown:
      case kStateError:
        heaterOff();
        if (msecInState() < kHeaterCooldownMsec) {
          // If error or cooldown, keep fan on while cooling.
          turnFanOn();
          sameState(kUpdateOffMsec);
        } else {
          turnFanOff();
          if (m_state.value() == kStateCooldown) {
            setState(kStateDisabled, kUpdateOffMsec);
          } else {
            sameState(kUpdateOffMsec);
          }
        }
        break;
      case kStateEnabled: {
        const float cmd = s_pid.command(temp, filt_d_temp, now_msec);
        heaterOn(cmd);
        turnFanOn();
        sameState(kUpdateOnMsec);
        break;
      }
      case kStateCommand: {
        const int test_command_msec = static_cast<int>(testCommandTime() * 1e3);
        if (test_command_msec <= 0 || msecInState() < test_command_msec) {
          heaterOn(m_test_command.value());
          turnFanOn();
          if (test_command_msec > 0) {
            const int msec_remaining = test_command_msec - msecInState();
            sameState(std::min(msec_remaining, kUpdateOnMsec));
          } else {
            sameState(kUpdateOnMsec);
          }
        } else {
          s_app.log().logf("Test command timed-out after %.1f sec.", msecInState() * 1e-3);
          heaterOff();
          turnFanOn();
          setState(kStateCooldown, kUpdateOffMsec);
        }
        break;
      }
    }

    s_app.mqttSend(s_vg);
    // Send config variables unless marked kNoPublish.
    s_app.mqttSend(s_cvg, VariableBase::kNoPublish | VariableBase::kConfig);
    s_app.mqttSend(s_cmdvg, VariableBase::kConfig);
  }

  void writeHtmlStatusTable(String* out) {
    html::writeTableStart(out, "Status");
    html::writeRowInto(out, s_pid.target());
    html::writeRowInto(out, m_heat_mode);
    html::writeRowInto(out, m_fan_mode);
    html::writeRowInto(out, s_relay_fan.isHighVar());
    html::writeRowInto(out, s_shtc3_enclosure.temperatureVar());
    html::writeRowInto(out, s_shtc3_enclosure.humidityVar());
    html::writeRowInto(out, s_shtc3_room.temperatureVar());
    html::writeRowInto(out, s_shtc3_room.humidityVar());
    html::writeTableEnd(out);
  }

  void toJson(JsonObject& json) {
    json["state"] = state_names[m_state.value()];
    json["state_idx"] = static_cast<int>(m_state.value());
    json["tempEnclosure"] = s_shtc3_enclosure.temperature();
    json["humEnclosure"] = s_shtc3_enclosure.humidity();
    json["tempRoom"] = s_shtc3_room.temperature();
    json["humRoom"] = s_shtc3_room.humidity();
    json["tempFilt"] = s_temp_filter.value();
    json["tempDFilt"] = s_d_temp_filter.value();
    json["target"] = s_pid.target().value();
    json["setTemp"] = m_set_temp.value();
    json["heater"] = s_pwm_heater.dutyF();
    json["fan"] = s_relay_fan.isHigh();
    json["heatMode"] = m_heat_mode.value();
    json["fanMode"] = m_fan_mode.value();
    json["cmdP"] = s_pid.p_term();
    json["cmdI"] = s_pid.i_term();
    json["cmdD"] = s_pid.d_term();
    json["cmdFF"] = s_pid.ff_term();
  }

 protected:
  void setState(State state, unsigned msec) {
    if (m_state.value() != state) {
      s_app.log().logf("state %u -> %u.", static_cast<unsigned>(m_state.value()),
                       static_cast<unsigned>(state));
      m_state = state;
      m_last_state_change_msec = millis();
      s_pid.initialize();
      m_heat_mode = enabled() ? kHeat : kOff;
    }
    m_scheduler.runIn(1, [this]() { update(); });
    // Internal LED follows enable/disable state.
    if (enabled()) {
      s_blink.on();
    } else {
      s_blink.off();
    }
  }
  void sameState(unsigned msec) {
    m_scheduler.runIn(msec, [this]() { update(); });
  }

  void mqttSetMode(const char* topic, const char* payload, size_t len) {
    if (0 == strncmp(payload, kOff, len)) {
      delaySetEnable(false);
    } else if (0 == strncmp(payload, kHeat, len)) {
      delaySetEnable(true);
    } else {
      s_app.log().logf("setMode('%s', (%d)'%s') unknown mode", topic, static_cast<int>(len),
                       payload);
    }
  }
  void mqttSetFanMode(const char* topic, const char* payload, size_t len) {
    if (0 == strncmp(payload, kOff, len)) {
      m_fan_mode = kOff;
      turnFanOff();
    } else if (0 == strncmp(payload, kHigh, len)) {
      m_fan_mode = kHigh;
      turnFanOn();
    } else {
      s_app.log().logf("setMode('%s', (%d)'%s') unknown mode", topic, static_cast<int>(len),
                       payload);
    }
  }
  void mqttSetTargetTemp(const char* topic, const char* payload, size_t len) {
    float temp = 0.0f;
    if (1 != sscanf(payload, "%f", &temp)) {
      s_app.log().logf("setTargetTemp('%s', (%d)'%s') failed to parse payload temp", topic,
                       static_cast<int>(len), payload);
    } else if (temp > kTargetTempMax) {
      s_app.log().logf("setTargetTemp('%s', %g) target too high", topic, temp);
    } else if (temp < kTargetTempMin) {
      s_app.log().logf("setTargetTemp('%s', %g) target too low", topic, temp);
    } else {
      setTargetTemp(temp);
    }
  }
  bool haDiscovery(HADiscovery* had, JsonDocument* json) {
    json->clear();

    {
      // The variable is not used for addRoot() -- this just sets device informaton.
      HADiscovery::Entry entry(m_temp_min_ok, ha::device_type::kClimate, nullptr);
      had->addRoot(json, entry);
    }
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
void loop() {
  og3::s_app.loop();

  // Detect button-down transition.
  static unsigned s_button_count = 0;
  const bool button_was_high = og3::s_button_reader.isHigh();
  og3::s_button_reader.read();
  if (!button_was_high && og3::s_button_reader.isHigh()) {
    og3::s_temp_control.toggleEnable();
    s_button_count += 1;
    og3::s_app.log().logf("button -> high");
  } else if (button_was_high && !og3::s_button_reader.isHigh()) {
    og3::s_app.log().logf("button -> low");
  }
}

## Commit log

2024-09-28 Initial import (#1)
    [Dough133_test.scad, DoughLee2.kicad_pcb, DoughLee2.kicad_sch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]
2024-10-13 shtc3 fixes (#4)
    Updates to KiCAD design:
    - Fix library locations
    - Update some footprints and symbols
    - Added missing +3.3V to SHTC3
    - Removed jumper from edge-connector power and replaced with wire
    main.cpp: Tried to fix i2c initialization for room SHTC3 sensor in ebox.
    README: point to kicad repositories
    [DoughLee2.kicad_pcb, DoughLee2.kicad_sch, ESP32-NoSerial.kicad_sch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]
2026-02-02 Version 0.9.95: input shaping (#8)
    - Update og3 to 0.4.3.
    - Use input shaping to avoid overshooting temperature setpoint.
    - Fan control now overrides fan relay when high.
    - Report actual fan relay state.
    [main.cpp]
2026-02-11 version 0.9.96 (#10)
    * Start sending data via MQTT when first turned on.
    Before, it only sent data after control started.
    * Added a test state. It sends 'cmd_test' as constant PWM command.
    * version -> 0.9.96
2026-02-12 version 0 9 96 (#12)
    * Allow 70deg max in enclosure, show pwm when cmd starts
    * Disable debug prints.
    * print SHTC3 room reading failure warning only once
    [main.cpp]
2026-02-12 pwm -> Watt analysis (#11)
    - Script or for fitting pwm -> Watts and generating a plotly plot for the blog.
    - Added ruff support for the Python: pre-command and github-actions.
    [Dough133_test.scad, board.scad, box.scad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]
2026-02-14 version -> 0.9.97: add optional timeout for test-command (#13)
    Add optional timeout for test-command E.g., this can be used to deliver a (near) impulse.
    Upgrade og3 version to fix PID error.
    Add cooler cool-down analysis by Gemini.
    Update README
    [2026-2-11-cooling.csv]
2026-03-30 Version -> 1.0.0 (#14)
    ### Added
    - New responsive Svelte web interface for status monitoring and configuration.
    - JSON API for full device control and status reporting.
    - Standardized `camelCase` naming for all API keys and internal variables.
    - Manual fan control via web UI.
    - Integrated "Run Test" command button in configuration page.
    - Switch to `min_spiffs.csv` partition table to support OTA updates with the new web assets.
    ### Changed
    - Reorganized web server routes (legacy HTML interface moved to `/old`).
    - Improved PID control stability and configuration.
    - Standardized variable naming across firmware and frontend.
    [main.cpp]
2026-11-02 Release v1.1.0: og3 0.7.0 upgrade, HA discovery fixes, and software-monitored safety watchdog (#23)
    ## Summary
    - **Software-Monitored Hardware Safety Watchdog**: Replaced the autonomous hardware LEDC PWM safety signal on `GPIO19` with a `200 Hz` `esp_timer` pulse generator gated by both `loop()` (`250 ms` timeout) and `TempControl::update()` (`2.5 s` timeout) heartbeats, ensuring the hardware monostable (`U4` `SN74LVC1G123`) cuts heater power if either the main loop or control loop stalls.
    - **NTP & WiFi Watchdog**: Added `og3::Ntp` time synchronization and `og3::WifiWatchdog` recovery.
    - **MQTT Mode & SSL/TLS Configuration**: Exposed MQTT broker mode (`Home Assistant` / `Adafruit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
